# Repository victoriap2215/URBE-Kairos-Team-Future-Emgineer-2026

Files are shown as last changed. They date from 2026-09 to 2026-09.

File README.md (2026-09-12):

# Índice

# Índice

* [1. Nuestro Equipo](#1-nuestro-equipo)
  * [1.1 Integrantes](#11-integrantes)
  * [1.2 Nuestro Objetivo](#12-nuestro-objetivo)
  * [1.3 Contenido de la carpetas](#13-contenido-de-las-carpetas)
* [2. El Robot y Diseño Mecánico](#2-el-robot-y-diseño-mecánico)
  * [2.1 Chasis y Estructura](#21-chasis-y-estructura)
  * [2.2 Sistema de Dirección](#22-sistema-de-dirección)
  * [2.3 Sistema de Tracción](#23-sistema-de-tracción)
  * [2.4 Fotos del vehículo](#23-fotos-del-vehículo)
* [3. Apartado Electrónico](#3-apartado-electrónico)
  * [3.1 Microcontrolador y Sensores](#31-microcontrolador-y-sensores)
  * [3.2 Controlador de Motores](#32-controlador-de-motores)
  * [3.3 Baterías y Alimentación](#33-baterías-y-alimentación)
  * [3.4 Esquemas de Conexión](#34-esquemas-de-conexión)
* [4. Software y Control](#4-software-y-control)
  * [4.1 Visión Artificial](#41-visión-artificial)
  * [4.2 Algoritmo de Navegación](#42-algoritmo-de-navegación)
  
---

## 1. Nuestro Equipo
Somos Kairos, un grupo de estudiantes universitarios dedicados a la robótica, la automatización y la innovación tecnológica. 
### 1.1 Integrantes
<table>
  <tr>
    <td width="30%" valign="top">
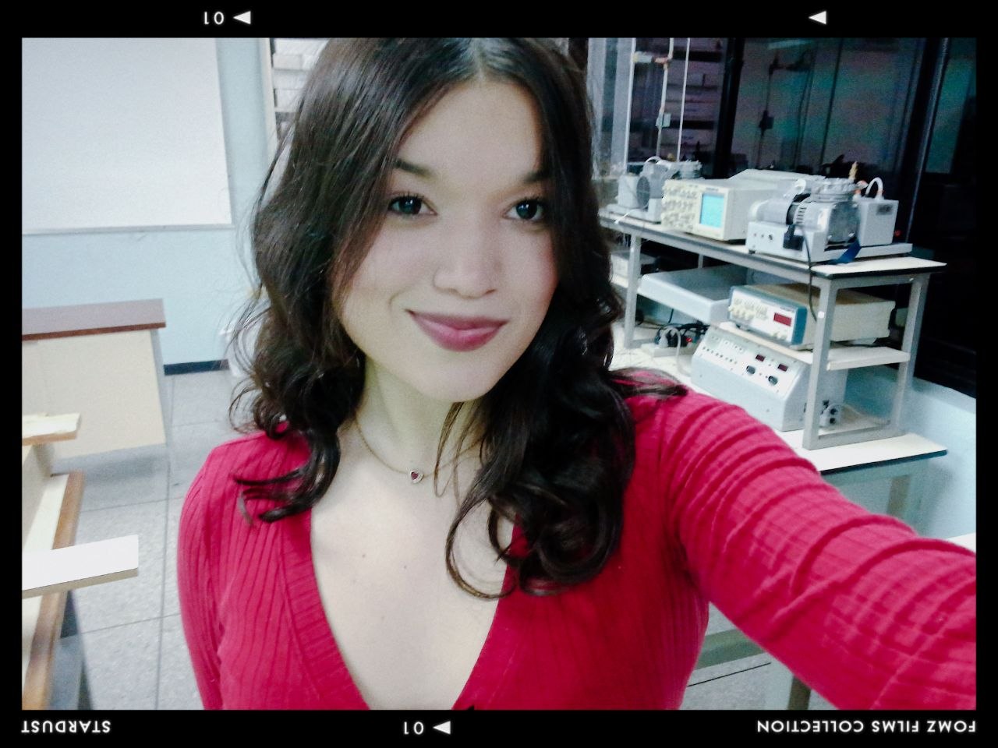
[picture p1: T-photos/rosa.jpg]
Rosalba Rodríguez
      
    </td>
    <td valign="top">
      <h3>Rosalba Rodríguez</h3>
      <p>🎂 <b>Edad:</b> [21] años</p>
      <p>🧑‍💻 <b>Rol:</b> Hardware / Electrónica</p>
      <hr>
      <p>🔩 <b>Habilidades:</b></p>
      <ul>
        <li>Estudiante de Ing. Electrónica (Mención Automatización y Control).</li>
        <li>Desarrollo de sistemas de control para robótica autónoma.</li>
      </ul>
      <p>
    </td>
  </tr>
</table>
<table>
  <tr>
    <td width="30%" valign="top">
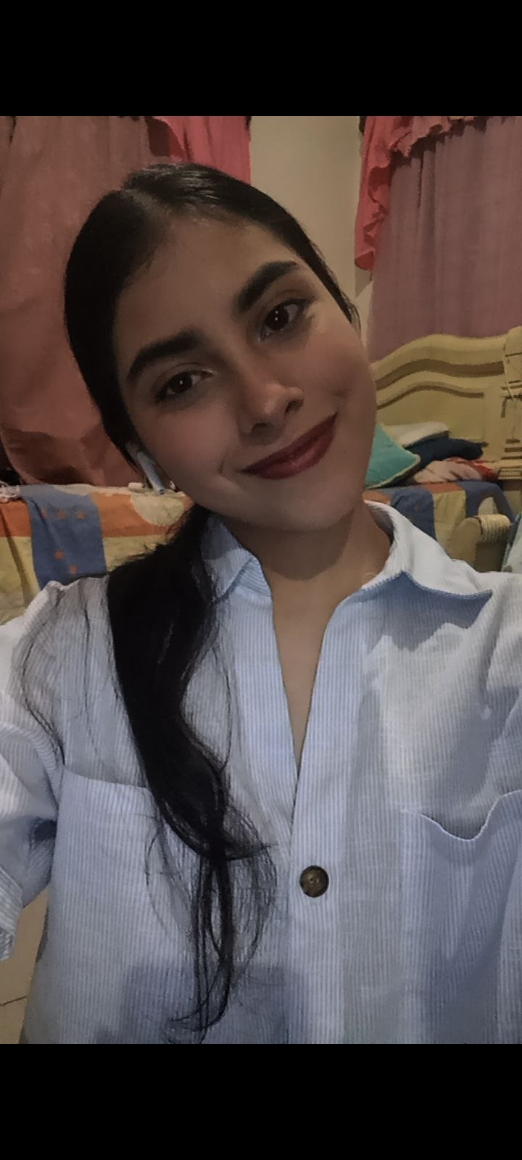
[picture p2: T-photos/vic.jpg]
Victoria Perozo
      
    </td>
    <td valign="top">
      <h3>Victoria Perozo</h3>
      <p>🎂 <b>Edad:</b> [20] años</p>
      <p>🧑‍💻 <b>Rol:</b> Documentación y Hardware / Electrónica</p>
      <hr>
      <p>🔩 <b>Habilidades:</b></p>
      <ul>
        <li>Estudiante de Ing. Electrónica (Mención Telecomunicaciones).</li>
        <li>Diseño y simulación de circuitos electrónicos.</li>
        <li>Desarrollo de sistemas de control para robótica autónoma.</li>    </td>
  </tr>
</table>
<table>
  <tr>
    <td width="30%" valign="top">
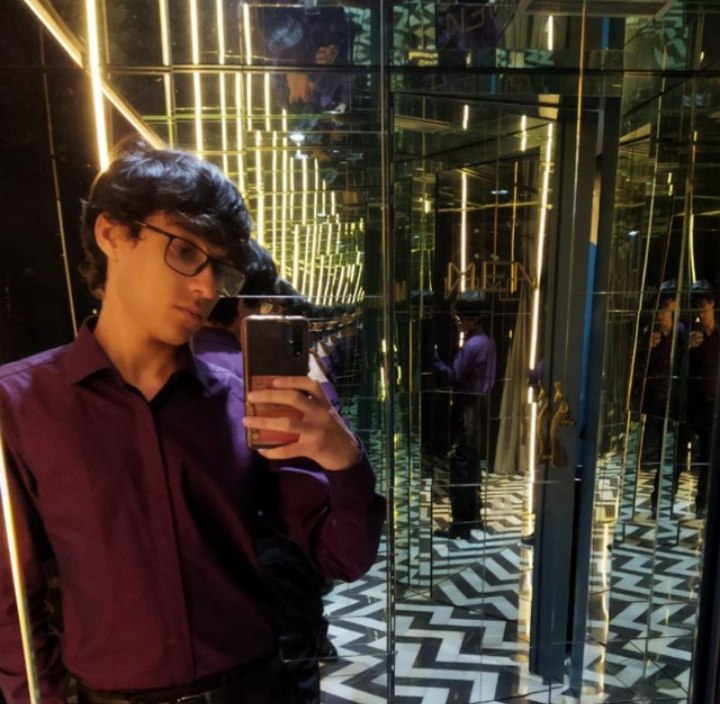
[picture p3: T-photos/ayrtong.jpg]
Ayrton Mrarcano
      
    </td>
    <td valign="top">
      <h3>Ayrton Marcano</h3>
      <p>🎂 <b>Edad:</b> [19] años</p>
      <p>🧑‍💻 <b>Rol:</b> Programación / Electrónica</p>
      <hr>
      <p>🔩 <b>Habilidades:</b></p>
      <ul>
        <li>Estudiante de Ing. Informatica.</li>
        <li>Programación de microcontroladores y sensores.</li>
        <li>Desarrollo de sistemas de control para robótica autónoma.</li>
    </td>
  </tr>
</table>

### 1.2 Nuestro Objetivo
Este proyecto tiene como objetivo diseñar, construir y programar un robot autónomo capaz de superar una serie de desafíos de obstáculos para la competición WRO Future Engineers. El equipo Kairos se inspiró en la aplicación de principios de ingeniería y en la resolución creativa y eficiente de problemas, impulsados por la pasión por la innovación y el aprendizaje práctico. 

Buscamos desarrollar un sistema fiable y eficiente que muestre nuestras competencias técnicas y de trabajo en equipo, y que además ofrezca una experiencia formativa profunda. Para lograrlo seguimos un proceso sistemático: investigación, prototipado, pruebas de laboratorio e iteraciones continuas. Mantenemos documentación detallada para facilitar la transferencia de conocimiento y asegurar un flujo de trabajo ordenado a lo largo del proyecto

### 1.3 Contenido de las carpetas
Contenido (Github) 
### *t-photos* contiene fotos del equipo

### *v-photos* contiene 6 fotos del vehículo desde varios ángulos

### *video* contiene el archivo video.md con el enlace a nuestro canal de YouTube y los vídeos correspondientes

### *models* es para los archivos 3D que usamos para imprimir nuestras piezas

### *other* incluye otros archivos que pueden usarse para entender cómo preparar el vehículo para la competición. Incluye documentación, conjuntos de datos, especificaciones de hardware, protocolos de comunicación, descripciones, etc.

### *schemes* contiene diagramas esquemáticos de los componentes electromecánicos que ilustran todos los elementos (componentes electrónicos y motores) utilizados en el vehículo y cómo se conectan entre sí.

### *src* contiene código de software de control para todos los componentes programados para participar en la competición

## 2. El Robot y Diseño Mecánico

### 2.1 Chasis y Estructura
Detalles de la estructura del vehículo.
 Se ha diseñado e impreso en 3D un complejo sistema de suspensión delantera de brazos superpuestos (double-wishbone) con amortiguadores simulados. Esto no solo eleva el chasis, sino que garantiza que las ruedas mantengan un contacto constante y uniforme con el tapete, incluso al pasar sobre pequeñas irregularidades o cables, asegurando una tracción máxima y constante.
Chasis Modular Elevado (Imagen 0): El chasis azul impreso en 3D ahora sitúa toda la electrónica crítica (Arduino Mega, portabaterías de 18650, driver de motores L298N) por encima del eje de las ruedas. Esto libera espacio inferior y evita cualquier tipo de rozamiento.
Ruedas de Mayor Diámetro y Agarre: Se seleccionaron ruedas con un compuesto de goma con mejor coeficiente de fricción y mayor diámetro para contribuir a la elevación general y mejorar la capacidad de superar obstáculos menores.

### 2.2 Sistema de Dirección
### Servomotor: MG996R

<table>
  <tr>
    <td width="30%" valign="top" align="center">
      <br>
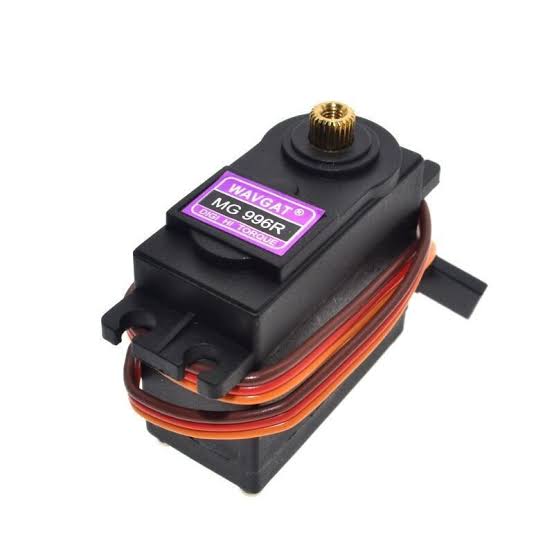
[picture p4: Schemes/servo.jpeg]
Servomotor MG996R
      
    </td>
    <td valign="top">
      <h4>Especificaciones:</h4>
      <table>
        <tr><td><b>Velocidad de operación</b></td><td>0.14 s/60°</td></tr>
        <tr><td><b>Voltaje de operación</b></td><td>6v DC</td></tr>
        <tr><td><b>Corriente de operación</b></td><td>500 mA – 900 mA</td></tr>
        <tr><td><b>Corriente de bloqueo</b></td><td>2.5 A</td></tr>
        <tr><td><b>Par de bloqueo</b></td><td>11.0 kg·cm</td></tr>
        <tr><td><b>Material de engranajes</b></td><td>metálico</td></tr>
        <tr><td><b>Peso</b></td><td>55 g</td></tr>
        <tr><td><b>Tipo de servo</b></td><td>Estándar / Posicional (180°)</td></tr>
        <tr><td><b>Datasheet</b></td><td><a href="URL_DEL_DATASHEET" target="_blank">MG996R Tower-Pro</a></td></tr>
      </table>
    </td>
  </tr>
</table>

### Dimensión mecánica
dim servo

Para hacer una buena elección se hizo la comparación con el micro-servo SG90. Aunque ambos se controlan por PWM y tienen un recorrido de 180°, el SG90 usa engranajes de plástico, opera a un voltaje de 4.8V y entrega un torque máximo de apenas 1.8 kg·cm, lo que lo hace más propenso al desgaste en sus engranajes o romperse debido al peso del chasis en movimiento, en cambio, el MG996R ofrece un torque de bloqueo que alcanza aproximadamente 11 kg·cm a 6V, por lo que dispone de un margen de trabajo mucho mayor para vencer la resistencia del sistema de varillas, la fricción del pivote y las irregularidades de la pista, lo que le da la robustez necesaria para mantener la alineación de las ruedas y reducir el desgaste en el sistema de varillas de dirección. 

### *Motivo de la elección:* 

Para la dirección del robot, elegimos el servomotor MG996R de giro estándar, por su buena resistencia mecánica y sus engranajes metálicos, que son importantes para soportar las cargas del eje delantero. Además, su control por PWM facilita conectarlo directamente con el microcontrolador, lo que permite una respuesta rápida y precisa. 

La dirección fue diseñada bajo la geometría Ackermann porque se busca que el robot tenga un giro más suave y eficiente, reduciendo el deslizamiento de las ruedas. A diferencia de un sistema de dirección paralela, esta configuración mejora la maniobrabilidad en espacios pequeños y ayuda a mantener una alineación más exacta al estacionar o esquivar obstáculos. 

### *Justificación técnica:* 

ackerman

Utilizamos un sistema de dirección Ackermann diseñado y fabricado a medida mediante impresión 3D. Este mecanismo permite que las ruedas delanteras giren con ángulos ligeramente diferentes en cada curva, de modo que ambas sigan trayectorias concéntricas hacia un mismo punto sobre el eje trasero. Esta configuración mejora la estabilidad y la precisión en los giros cerrados. El diseño fue ajustado de forma interactiva en FreeCAD, modificando los puntos de giros y los ángulos de dirección hasta lograr una aproximación adecuada a la configuración Ackermann. 

La calibración del sistema se realizó verificando la posición neutra del servomotor antes del montaje definitivo, es decir, lo primero que se realizó fue conectar el servo al Arduino y ordenarle un ángulo de 90° antes de su montaje, para así asegurar que el motor estuviera centrado y no forzar ni romper las piezas. Con el servo fijo en ese punto, se procedió al montaje del brazo de dirección y acoplamiento de las varillas de la geometría Ackermann intentando que las ruedas delanteras quedaran lo más centradas posible. A partir de esa referencia, se hicieron pruebas en la pista y ajustes en el código para corregir desviaciones y asegurar que el giro a ambos lados fuera simétrico. De esta manera, se aseguró que el sistema quedara centrado y que las correcciones de dirección respondieran con precisión a las órdenes del microcontrolador.  

La geometría Ackermann fue adaptada a las dimensiones y curvas de la pista para asegurar que el vehículo tuviera buena reacción a las curvas cerradas y la mínima pérdida de adherencia posible. Por consiguiente, se ajustaron los ángulos de dirección y la posición de los puntos de giro en el modelo impreso en 3D, buscando que las ruedas delanteras trazaran una trayectoria coherente con el radio de curvatura de la pista durante las maniobras. Este ajuste permitió mejorar la estabilidad del robot, especialmente en cambios de dirección bruscos y en el paso por obstáculos. 
 
### *Cálculos:* 

### Ecuación Fundamental
cot(θ o ) - cot(θ i ) = W / L

W : Distancia entre pivotes de dirección (batalla)
L : Distancia entre ejes

### Relación de Velocidades en Curva
ω o / ω i = (R + W/2) / (R - W/2)

ω o : Velocidad angular de la rueda exterior.
ω i : Velocidad angular de la rueda interior.
R : Radio de giro del centro del eje.

### *Montaje:* 

El servomotor está en una plataforma de soporte frontal integrada en el chasis, la cual conecta con el varillaje del mecanismo de dirección.  El diseño modular permite realizar ajustes o cambios de componentes de manera sencilla. 

### 2.3 Sistema de Tracción
### Motor: Motorreductor DC

<table>
  <tr>
    <td width="30%" valign="top" align="center">
      <br>
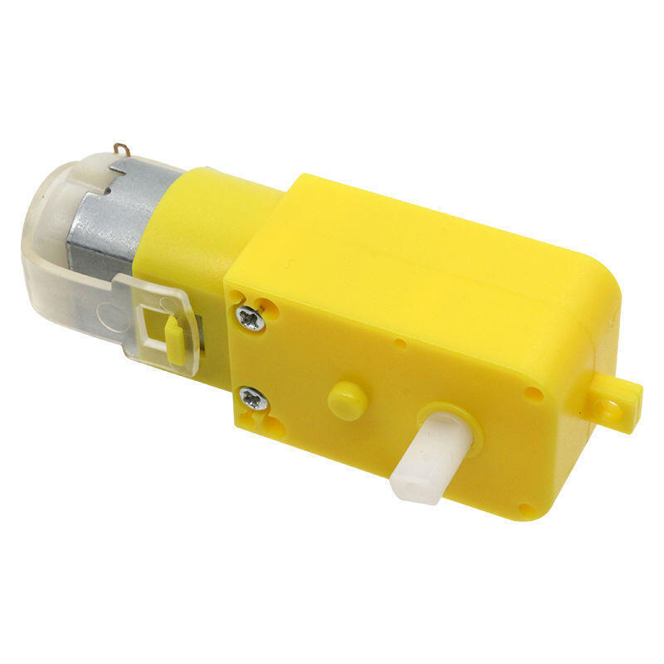
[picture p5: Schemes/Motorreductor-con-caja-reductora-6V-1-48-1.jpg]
Motorreductor DC
      
    </td>jp
    <td valign="top">
      <h4>Especificaciones:</h4>
      <table>
        <tr><td><b>Voltaje</b></td><td>12v DC</td></tr>
        <tr><td><b>Velocidad sin carga (RPM)</b></td><td>200rpm</td></tr>
        <tr><td><b>Par de motor de pérdida</b></td><td>1.7 kg-cm</td></tr>
        <tr><td><b>Par máximo de eficiencia</b></td><td>0.34 kg-cm</td></tr>
        <tr><td><b>Relación de cambios</b></td><td>1:100</td></tr>
        <tr><td><b>Corriente nominal</b></td><td>0.04 A</td></tr>
        <tr><td><b>Corriente de pérdida</b></td><td>0.67 A</td></tr>
        <tr><td><b>Material de engranajes</b></td><td>metálico</td></tr>
        <tr><td><b>Datasheet</b></td><td><a href="https://www.bolanosdj.com.ar/MOVIL/ARDUINO2/MotoresConRuedasArd.pdf" target="_blank">MotoresConRuedasArd.pdf</a></td></tr>
      </table>
    </td>
  </tr>
</table>

### Dimensión mecánica
dig moto

### *Motivo de la elección*

El motorreductor amarillo DC fue seleccionado por su diseño ligero, económico y su facilidad de integración dentro de nuestro chasis. Su caja reductora integrada permite una transmisión directa y eficiente hacia las ruedas, proporcionando el par necesario para mantener una buena tracción en pistas planas dentro de una arquitectura modular.

Al no contar con un encoder (codificador) integrado para el conteo de vueltas, se incorporó un giroscopio que ofrece una retroalimentación de movimiento precisa. Esto asegura que los desplazamientos del robot sean exactos, compensando la ausencia de sensores de efecto Hall y reduciendo el margen de error al tomar curvas cerradas.

### *Justificación técnica* 

Elegimos el motorreductor amarillo DC con su relación de reducción interna (1:48) porque nos ofrece el balance ideal entre torque, velocidad de respuesta y consumo energético. Esta configuración permite alcanzar la velocidad requerida en las ruedas para que los sensores de visión artificial y los sensores ultrasónicos ejecuten la captura y el procesamiento de datos en tiempo real con alta estabilidad, evitando desincronizaciones en las lecturas durante los giros.

Utilizando los modelos de transferencia de torque y considerando el peso total del chasis junto con la fricción de los ejes, los cálculos determinan que el torque requerido para vencer la fricción estática inicial y poner en marcha el robot se encuentra muy por debajo del torque máximo de pérdida especificado para estos motores. Este margen garantiza un factor de seguridad óptimo sobre el torque mínimo de arranque, asegurando que los motores operen de forma continua en su zona de mayor eficiencia sin sobrecalentamiento.

### *Diferencial de engranaje (Diseño principal)*

Originalmente se diseñó un sistema de engranajes diferencial impreso en 3D para ser acoplado al conjunto del motorreductor amarillo. Este mecanismo permitiría que las ruedas traseras (izquierda y derecha) giraran a velocidades independientes durante las curvas, optimizando el desplazamiento fluido y mejorando la estabilidad del robot en giros exigentes. Sin embargo, debido a fallos en la manufactura de las piezas mecánicas, no fue posible su implementación en el prototipo final.
Solución del diseño

Durante la fase de ensamblaje se identificó un error de tolerancia en la impresión de los engranajes internos del diferencial (el anillo y los piñones satélite). Ante la imposibilidad de reimprimir estas piezas a tiempo para las pruebas, se sustituyó la caja del diferencial por un sistema de transmisión de eje rígido directo.

Aunque esta modificación elimina la capacidad mecánica de variar la velocidad entre ambas ruedas al girar, el efecto se compensa a través de código: el software utiliza los datos del giroscopio para ajustar la aceleración y gestionar electrónicamente la trayectoria del vehículo en las curvas.

### Fotos del vehículo

### 1.2 Imágenes del Robot

<table>
  <tr>
    <td align="center">
      <b>Vista frontal</b><br>
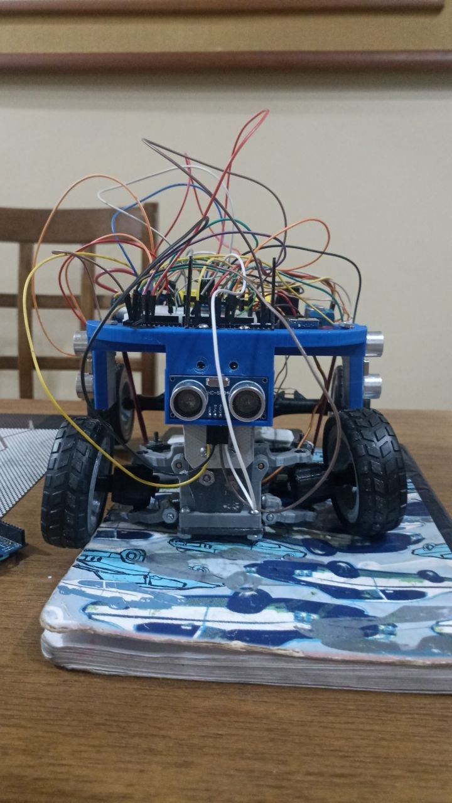
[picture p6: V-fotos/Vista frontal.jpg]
Vista frontal
      
    </td>
    <td align="center">
      <b>Vista posterior</b><br>
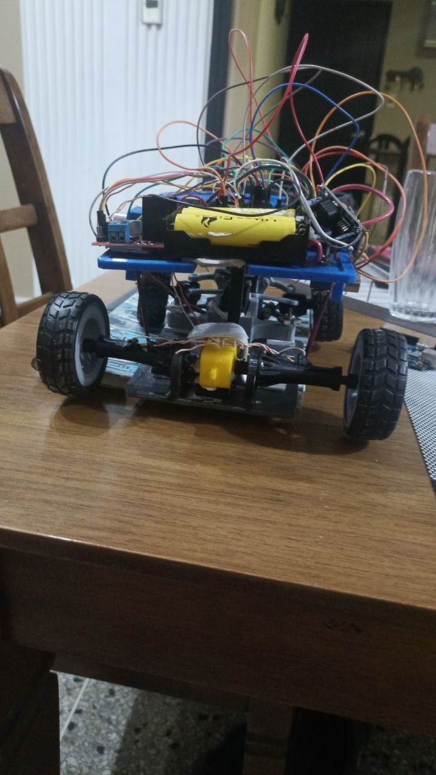
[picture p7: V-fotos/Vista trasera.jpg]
Vista posterior
      
    </td>
    <td align="center">
      <b>Vista lateral izquierda</b><br>
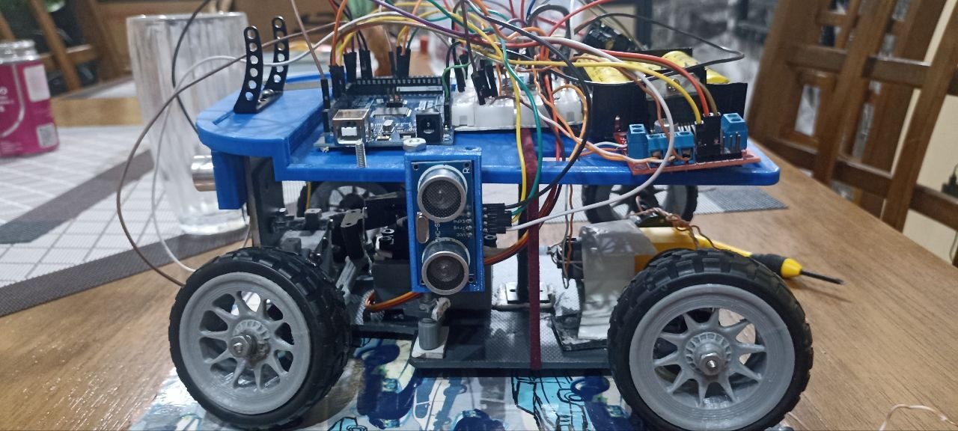
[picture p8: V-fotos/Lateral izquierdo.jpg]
Vista lateral izquierda
      
    </td>
  </tr>
  <tr>
    <td align="center">
      <b>Vista lateral derecha</b><br>
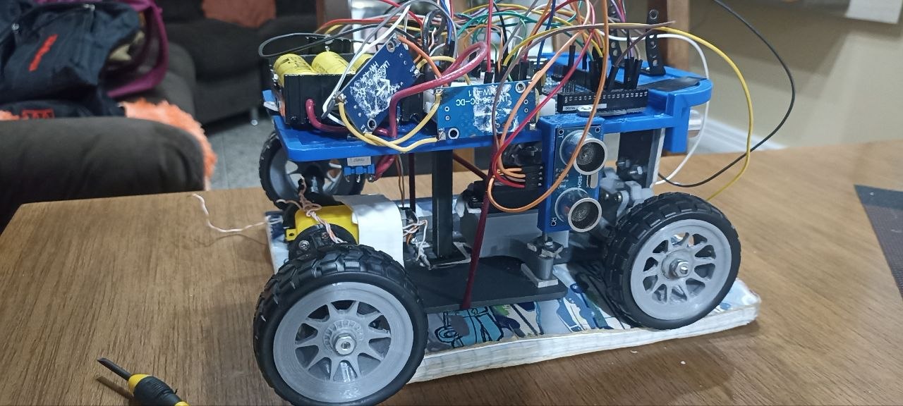
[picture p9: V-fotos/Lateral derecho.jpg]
Vista lateral derecha
      
    </td>
    <td align="center">
      <b>Vista superior</b><br>
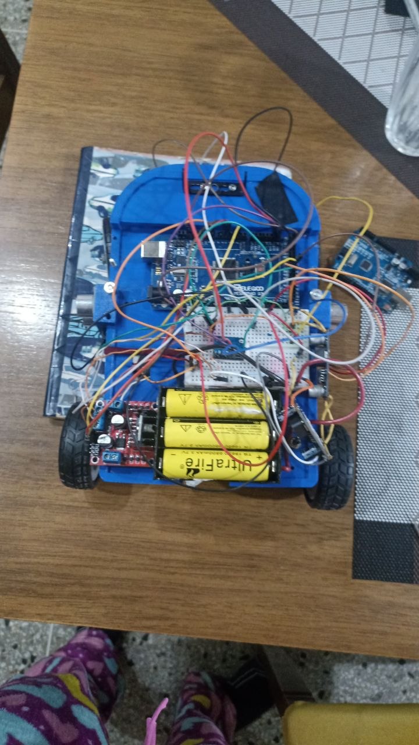
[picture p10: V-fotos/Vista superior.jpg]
Vista superior
      
    </td>
    <td align="center">
      <b>Vista inferior</b><br>
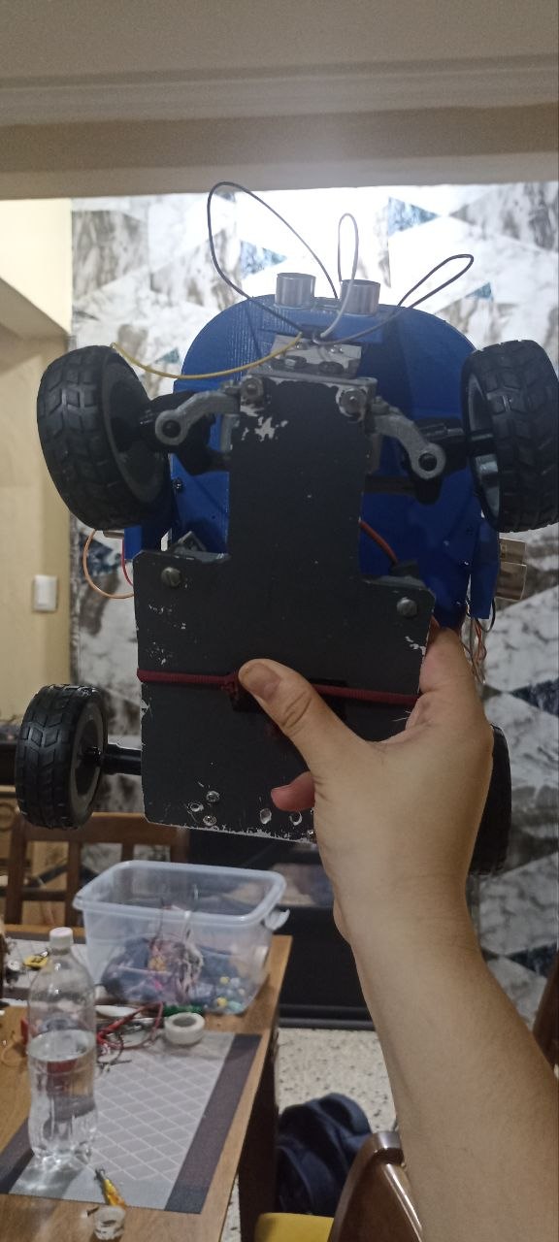
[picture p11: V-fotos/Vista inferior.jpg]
Vista inferior
      
    </td>
  </tr>
</table>

## 3. Apartado Electrónico
### 3.1 Microcontrolador y Sensores
### Microcontrolador: Arduino Mega2560

<table>
  <tr>
    <td width="30%" valign="top" align="center">
      <br>
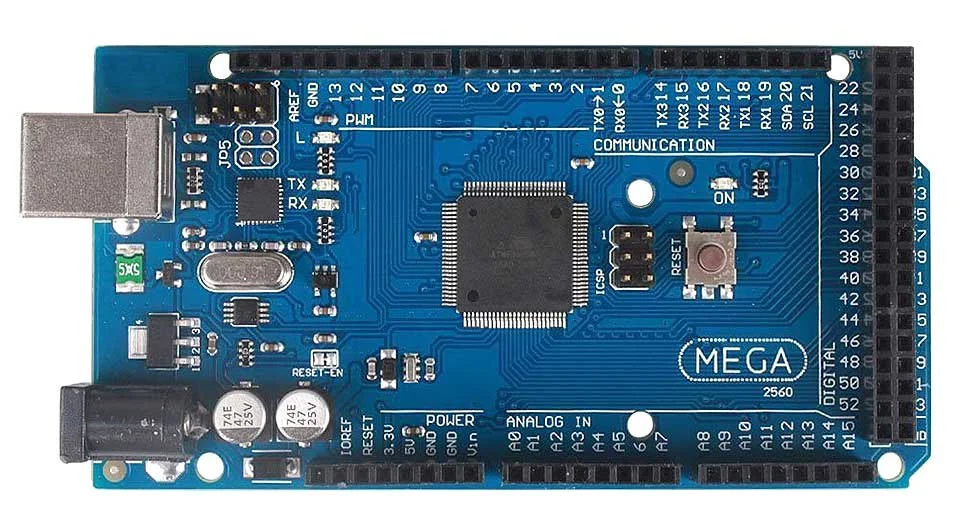
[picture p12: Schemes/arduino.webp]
Arduino Mega2560
      
    </td>
    <td valign="top">
      <h4>Especificaciones:</h4>
      <table>
        <tr><td><b>Microcontrolador</b></td><td>ATmega2560</td></tr>
        <tr><td><b>Coprocesador Inalámbrico</b></td><td>ESP8266 integrado (Para conectividad WiFi)</td></tr>
        <tr><td><b>Voltaje de operación</b></td><td>5 V DC</td></tr>
        <tr><td><b>Voltaje de Entrada</b></td><td>7V a 12V DC</td></tr>
        <tr><td><b>Pines I/O Digitales</b></td><td>54 (de los cuales 15 proporcionan salida PWM)</td></tr>
        <tr><td><b>Pines de Entrada Analógica</b></td><td>16</td></tr>
        <tr><td><b>Memoria Flash</b></td><td>256 KB (de los cuales 8 KB son usados por el bootloader)</td></tr>
        <tr><td><b>Memoria SRAM / EEPROM</b></td><td>8 KB / 4 KB</td></tr>
        <tr><td><b>Datasheet</b></td><td><a href="https://admin.arsbook.it/stempdf/LS-ELEGOO-MEGA.pdf" target="_blank">LS-ELEGOO-MEGA.pdf</a></td></tr>
      </table>
    </td>
  </tr>
</table>

### Motivo de la selección

El Arduino Mega 2560 actúa como el cerebro central de procesamiento de nuestro robot. Su arquitectura basada en el microcontrolador ATmega2560 ofrece una ejecución de muy baja latencia, lo cual resulta indispensable para responder en tiempo real a las lecturas del giroscopio MPU6050, el procesamiento del sistema de visión artificial y la evasión instantánea de obstáculos mediante los sensores ultrasónicos.

Elegimos esta tarjeta debido a la alta demanda de recursos de nuestra arquitectura electrónica y de control. Al integrar simultáneamente la cámara de visión artificial, los sensores ultrasónicos, el módulo IMU MPU6050, el servomotor de dirección y el driver de tracción, placas más compactas habrían agotado rápidamente sus pines disponibles y su memoria de trabajo. Además, este modelo incorpora un coprocesador inalámbrico ESP8266 integrado, lo que nos otorga conectividad WiFi para la transmisión de telemetría sin recargar las tareas principales del procesador central. Sus 54 pines digitales, 16 entradas analógicas y 4 puertos UART por hardware nos dan total libertad para mantener un esquema de cableado modular, ordenado y directo.

### Comparación con Arduino Uno y Nano

Al comparar la tarjeta seleccionada con un Arduino Uno o Nano tradicional, la diferencia más crítica radica en la capacidad de memoria y procesamiento. El Arduino Mega 2560 cuenta con 256 KB de memoria Flash y 8 KB de memoria SRAM, lo que representa hasta ocho veces más espacio para alojar algoritmos de control de trayectoria, cálculos de visión y librerías complejas sin correr el riesgo de colapsar la memoria del sistema durante la ejecución en pista.

Otra ventaja determinante es la disponibilidad de periféricos por hardware. Mientras que placas como el Uno poseen un solo puerto serie, el Mega 2560 ofrece 4 puertos UART independientes por hardware, lo que permite la comunicación simultánea con la cámara de visión y el monitor de depuración sin recurrir a emulaciones por software. Asimismo, sus 54 pines de entrada/salida digital evitan la saturación del controlador al conectar múltiples sensores y actuadores de forma dedicada, sumado a la conectividad WiFi integrada mediante el chip ESP8266 que no está presente en los modelos convencionales.

### Justificación de la ubicación

El Arduino Mega 2560 se posicionó en el centro geométrico del chasis con el objetivo principal de garantizar su protección estructural. Al ubicarse en la zona interna más resguardada del vehículo, la tarjeta queda protegida frente a posibles colisiones directas o roces accidentales contra las paredes del circuito durante la navegación.

Adicionalmente, esta posición estratégica optimiza la distribución general del cableado. Estar en el centro minimiza la distancia física hacia los componentes de la sección frontal (como la cámara de visión, el servomotor de dirección y los sensores ultrasónicos) y hacia la sección trasera (donde se encuentran el driver de potencia y el motor de tracción). Esto no solo ayuda a reducir el peso total de los cables y a equilibrar las masas del robot, sino que también disminuye notablemente el riesgo de interferencias electromagnéticas en las líneas de transmisión de datos.
Cámara, MPU6050, sensores ultrasónicos, etc.

### Sensor Ultrasónico: HC-SR04

<table>
  <tr>
    <td width="30%" valign="top" align="center">
      <br>
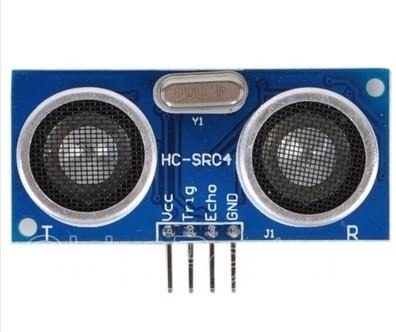
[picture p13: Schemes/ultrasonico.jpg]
Sensor Ultrasónico HC-SR04
      
    </td>
    <td valign="top">
      <h4>Especificaciones:</h4>
      <table>
        <tr><td><b>Modelo</b></td><td>HC-SR04</td></tr>
        <tr><td><b>Voltaje</b></td><td>5 V DC</td></tr>
        <tr><td><b>Corriente de trabajo</b></td><td>15 mA</td></tr>
        <tr><td><b>Corriente de reposo</b></td><td>&lt; 2mA</td></tr>
        <tr><td><b>Rango de medición</b></td><td>2 cm a 400 cm</td></tr>
        <tr><td><b>Ángulo de apertura</b></td><td>&lt; 15° (Cono de medición)</td></tr>
        <tr><td><b>Datasheet</b></td><td><a href="URL_DEL_DATASHEET" target="_blank">ULTRASONIC-HC-SR04.PDF</a></td></tr>
      </table>
    </td>
  </tr>
</table>

### Dimensiones mecánicas
dim sensor

### Motivo de la elección: 

Hemos integrado dos sensores ultrasónicos para la navegación en entornos con obstáculos, estos sensores son importantes para la detección de distancias de seguridad para evitar colisiones. El funcionamiento de estos dispositivos se basa en la emisión de pulsos sonoros y la medición del tiempo de retorno, lo que permite calcular la distancia a paredes o pilares con alta precisión, sin depender de las condiciones de luz, proporcionando seguridad para tareas como el aparcamiento en paralelo. 

Estos sensores ofrecen una ventaja competitiva frente a los infrarrojos, ya que al no depender de la iluminación del entorno permite una detección constante sobre cualquier tipo de material. Además, al tener una fácil conexión con el microcontrolador, permite una rápida integración. 

### Justificación de la ubicación: 

La aplicación de los ultrasónicos consta de tres sensores posicionados a los costados y al frente del robot, uno en el lado izquierdo y otro en el lado derecho. Esta distribución se aplica para compensar las zonas ciegas y complementar el campo de visión de la cámara. 

Al colocar la cámara en la parte frontal para el reconocimiento de colores y líneas de carrera, sus laterales se convierten en puntos ciegos en el campo de visión, debido al ángulo de su lente. Por ello, se decidió colocar los sensores posicionados hacia los laterales y al frente, para que cubran los puntos críticos de visión durante el recorrido, esta configuración nos ayuda a ejecutar maniobras como el aparcamiento en paralelo o la evasión de pilares en curvas cerradas, ya que permite medir la distancia de las paredes de la pista.

### Sensor de Orientación: Giroscopio

<table>
  <tr>
    <td width="30%" valign="top" align="center">
      <br>
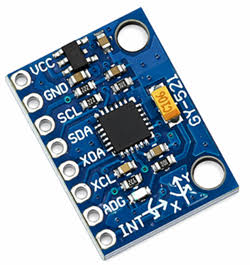
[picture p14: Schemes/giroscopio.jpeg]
Sensor MPU6050
      
    </td>
    <td valign="top">
      <h4>Especificaciones:</h4>
      <table>
        <tr><td><b>Modelo</b></td><td>MPU6050 (Acelerómetro + Giroscopio de 6 ejes)</td></tr>
        <tr><td><b>Voltaje</b></td><td>3.3 V a 5 V DC</td></tr>
        <tr><td><b>Corriente de operación</b></td><td>3.9 mA</td></tr>
        <tr><td><b>Protocolo de comunicación</b></td><td>I2C (pines SDA y SCL)</td></tr>
        <tr><td><b>Convertidores Analógico-Digital (ADC)</b></td><td>De 16 bits para cada eje</td></tr>
        <tr><td><b>Datasheet</b></td><td><a href="URL_DEL_DATASHEET" target="_blank">ps-mpu-6000a-00-mpu-6000-and-mpu-6050-datasheet.pdf</a></td></tr>
      </table>
    </td>
  </tr>
</table>

### Diagrama de bloque interno 
dig giro

### Motivo de la selección

El módulo MPU6050 es de suma importancia para la navegación y el control de rumbo de nuestro robot, especialmente debido a que nuestra configuración de tracción con el motorreductor amarillo DC no cuenta con encoders para medir directamente las revoluciones o vueltas de las ruedas, ante esta limitación, la Unidad de Medida Inercial (IMU) proporciona lecturas en tiempo real sobre la velocidad angular y el ángulo de orientación (yaw), permitiendo que el sistema realice correcciones continuas para mantener el rumbo o ejecutar giros exactos.

Elegimos el MPU6050 por ser una solución compacta e integral, ya que reúne en un solo chip un giroscopio de 3 ejes y un acelerómetro de 3 ejes, ofreciendo un sistema de navegación inercial completo de 6 grados de libertad (6-DOF). La mayor ventaja técnica de este módulo es su procesador interno Digital Motion Processor (DMP), el cual ejecuta de forma autónoma los cálculos matemáticos pesados para el filtrado de ruido y fusión de datos. Gracias a esto, el MPU6050 entrega los datos de orientación ya procesados y limpios, liberando de esa carga de trabajo a nuestro Arduino Mega 2560.

### Comparación con otras alternativas de orientación

Al comparar el MPU6050 con el uso de sensores individuales o con brújulas digitales magnéticas (como el HMC5883L), el MPU6050 presenta ventajas superiores de integración y precisión en robótica móvil. Las brújulas magnéticas son altamente susceptibles a las interferencias electromagnéticas generadas por el propio motorreductor amarillo DC en funcionamiento y por el cableado de potencia, lo que provoca desviaciones severas en la lectura de dirección. Al ser puramente inercial, el MPU6050 no se ve afectado por campos magnéticos externos.

Por otro lado, implementar sensores de inclinación o aceleración independientes requeriría mayor cableado en el bus I2C y obligaría al microcontrolador a ejecutar manualmente algoritmos de filtrado pesados (como el filtro de Kalman o complementario), consumiendo memoria y ciclos de procesamiento. El MPU6050 resuelve esto mediante su DMP interno, representando la opción más equilibrada entre precisión, bajo consumo y eficiencia de procesamiento.

### Justificación de la ubicación

El MPU6050 se ubicó en la zona central del chasis, situándose lo más cerca posible del centro de masa y del eje geométrico de rotación del robot. Esta ubicación es crítica, ya que situar el giroscopio lejos del centro de giro introduce aceleraciones centrípetas parasitarias durante las curvas, deformando las lecturas.
Adicionalmente, al estar montado de forma rígida sobre una sección estable del chasis, se reducen las vibraciones mecánicas generadas por el motorreductor amarillo y la rodadura, asegurando una transmisión constante de datos estables a través de las líneas de comunicación I2C.

### Cámara de Visión Artificial: HuskyLens 2

<table>
  <tr>
    <td width="30%" valign="top" align="center">
      <br>
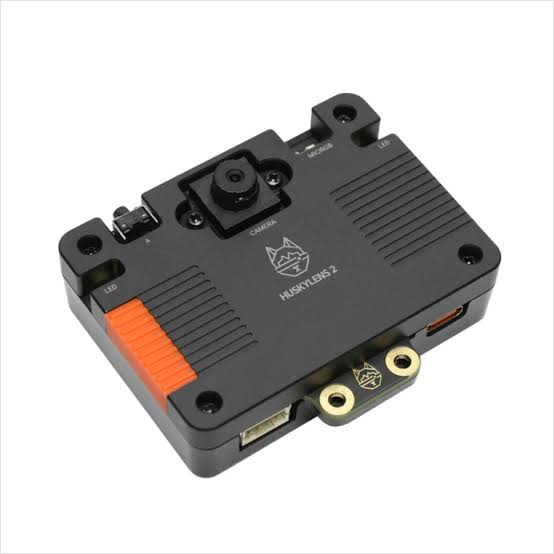
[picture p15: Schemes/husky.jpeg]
Cámara HuskyLens 2
      
    </td>
    <td valign="top">
      <h4>Especificaciones:</h4>
      <table>
        <tr><td><b>Procesador principal</b></td><td>Kendryte K230 Dual-Core a 1.6 GHz</td></tr>
        <tr><td><b>Sensor de imagen</b></td><td>GC2093 de 2.0 Megapíxeles (1/2.9", hasta 60 FPS)</td></tr>
        <tr><td><b>Pantalla</b></td><td>IPS táctil capacitiva de 2.4" (Resolución 640 × 480)</td></tr>
        <tr><td><b>Memoria</b></td><td>1 GB LPDDR4 RAM + 8 GB eMMC Flash</td></tr>
        <tr><td><b>Voltaje de operación</b></td><td>3.3V a 5.0V DC (a través del puerto Gravity o USB-C)</td></tr>
        <tr><td><b>Consumo de Corriente</b></td><td>1.5W – 3W (aprox. 300 mA a 600 mA a 5V)</td></tr>
        <tr><td><b>Tipo de Lente</b></td><td>Módulo intercambiable de lente modular</td></tr>
        <tr><td><b>Interfaces de datos</b></td><td>UART serial (baud rates 9600, 115200), I2C (dirección default 0x50), USB-C y Wi-Fi 6 (módulo opcional)</td></tr>
        <tr><td><b>Datasheet</b></td><td><a href="https://www.farnell.com/datasheets/3178377.pdf" target="_blank">3178377.pdf</a></td></tr>
      </table>
    </td>
  </tr>
</table>

### Motivo de la selección

La cámara de visión artificial HuskyLens 2 actúa como el sensor primario de percepción visual de nuestro robot. A diferencia de las cámaras convencionales, cuenta con un procesador dedicado Kendryte K230 Dual-Core a 1.6 GHz con aceleración por Inteligencia Artificial que procesa las imágenes internamente a 60 FPS. Esto permite detectar y rastrear objetos, firmas de color y marcadores visuales con alta precisión sin recargar de procesamiento al microcontrolador principal Arduino Mega 2560. Su diseño compacto y ligereza facilitan una integración eficiente en la estructura, utilizándose principalmente para:

 * Identificar y diferenciar el color y tipo de pilares u obstáculos en la pista.
 * Seguir líneas de ruta y límites del circuito.
 * Reconocer zonas de maniobra, señales y marcadores visuales en tiempo real.
 * 
### Comparación con la PixyCam2

Al comparar la HuskyLens 2 con la PixyCam2, la diferencia técnica más destacada se encuentra en la potencia de procesamiento y las capacidades de Inteligencia Artificial en el borde (Edge AI). Mientras que la PixyCam2 utiliza un procesador NXP dual-core a 204 MHz enfocado en la filtración de color por tono y saturación, la HuskyLens 2 integra un procesador Kendryte K230 a 1.6 GHz respaldado por 1 GB de memoria RAM LPDDR4 y 8 GB de almacenamiento eMMC. Esta diferencia de capacidad computacional permite a la HuskyLens 2 ejecutar modelos de visión e inferencias de IA significativamente más complejas y estables ante variaciones de escena.

Otra ventaja operativa determinante es la presencia de su pantalla táctil IPS de 2.4 pulgadas. La PixyCam2 carece de pantalla integrada, lo que obliga a conectar la cámara a una computadora portátil mediante el software PixyMon para ajustar o reentrenar algoritmos. En cambio, la HuskyLens 2 permite realizar la calibración, el aprendizaje de nuevas firmas de color y el ajuste de parámetros de detección directamente en la cámara mediante su interfaz táctil, acelerando drásticamente la puesta a punto del robot en la pista de competencia.

### Justificación de la ubicación y calibración

La HuskyLens 2 se montó de forma rígida en la parte frontal del vehículo sobre un soporte elevado. Esta posición otorga a la lente un ángulo despejado de la pista, permitiendo captar colores, referencias y límites sin que el chasis o el sistema de dirección obstaculicen la toma de imagen. La elevación estratégica permite anticipar las curvas, detectar con suficiente margen de distancia los pilares de color y enviar los datos de posición al Arduino para ejecutar giros suaves y precisos.
Para evitar errores de detección causados por variaciones en la iluminación del recinto (que suelen alterar la visión espectral y la temperatura de color), la cámara se calibra previamente a las pruebas.

### 3.2 Controlador de Motores
### Módulo Driver de Motores: Puente H L298N

<table>
  <tr>
    <td width="30%" valign="top" align="center">
      <br>
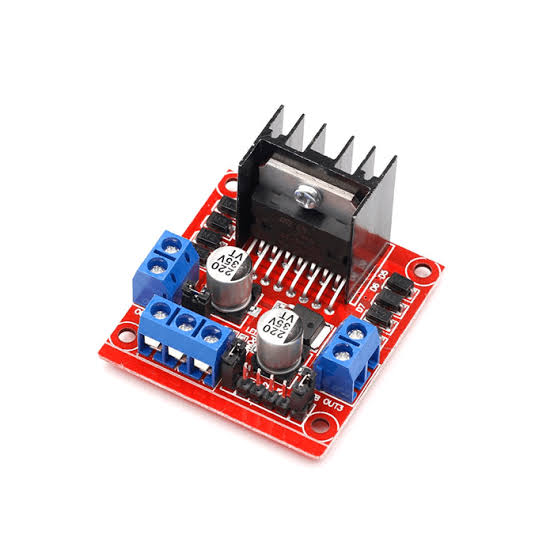
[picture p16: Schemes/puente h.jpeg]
Módulo Driver Puente H L298N
      
    </td>
    <td valign="top">
      <h4>Especificaciones:</h4>
      <table>
        <tr><td><b>Modelo</b></td><td>L298n (Módulo Driver Puente H Dual)</td></tr>
        <tr><td><b>Voltaje de entrada</b></td><td>5 V – 35 V (para los motores)</td></tr>
        <tr><td><b>Voltaje de lógica</b></td><td>5 V (para el Arduino)</td></tr>
        <tr><td><b>Corriente máxima</b></td><td>2A por canal</td></tr>
        <tr><td><b>Corriente continua</b></td><td>1A – 1.5A por motor (recomendado)</td></tr>
        <tr><td><b>Potencia máxima disipada</b></td><td>25W</td></tr>
        <tr><td><b>Motores controlables</b></td><td>2 motores DC o 1 paso a paso (bipolar)</td></tr>
        <tr><td><b>Datasheet</b></td><td><a href="URL_DEL_DATASHEET" target="_blank">Datasheet - L298 - Dual full-bridge driver</a></td></tr>
      </table>
    </td>
  </tr>
</table>

### Motivo de la elección

Para la gestión de la movilidad y el sistema de tracción, optamos por el módulo L298N como el puente H encargado de regular la velocidad mediante modulación por ancho de pulso (PWM) y el sentido de giro de nuestro motorreductor amarillo DC. Este módulo trabaja recibiendo señales de control de baja potencia desde el microcontrolador y las amplifica mediante su etapa de potencia para suministrar el voltaje adecuado al motor de tracción. Seleccionamos este componente por su plena compatibilidad con los niveles lógicos de 5V del Arduino Mega 2560, lo que garantiza una comunicación directa sin necesidad de acondicionadores de señal ni adaptadores de nivel.

Adicionalmente, el L298N nos facilita el montaje modular dentro del chasis gracias a sus borneras de tornillo integradas y a su robusto disipador térmico de aluminio. Estas ventajas mecánicas permiten asegurar las conexiones de alta corriente fuertemente con un destornillador, logrando un acople firme que previene desconexiones accidentales por vibración en la pista. Esto protege la estabilidad de toda la arquitectura electrónica, asegurando un suministro eléctrico aislado respecto a componentes sensibles como la cámara de visión artificial HuskyLens 2, el módulo inercial MPU6050 y los sensores ultrasónicos HC-SR04.

### Comparación con otros drivers de motores

Al comparar el L298N con alternativas populares como el driver TB6612FNG o el módulo L9110S, la principal ventaja para nuestro proyecto radica en la disipación térmica y la robustez mecánica. El TB6612FNG utiliza MOSFETs de mayor eficiencia que reducen la caída de voltaje interna; sin embargo, al ser un chip compacto de montaje superficial, no incluye conectores de bornera integrados. Conectar los cables exige soldadura directa o pines finos que resultan frágiles ante las vibraciones mecánicas continuas del vehículo.

Por otro lado, el módulo L9110S es de menor tamaño pero carece de un disipador de calor dedicado, lo que limita su capacidad para soportar picos de corriente bajo exigencia continua. El L298N destaca sobre ambas opciones por su capacidad de disipar corriente constante de hasta 2A por canal, su protección contra sobrecalentamiento gracias a su disipador integrado y la facilidad de mantenimiento que aportan sus terminales roscadas, convirtiéndolo en la opción más confiable para soportar la carga eléctrica del motorreductor amarillo DC a 12V.
Justificación técnica y gestión de potencia

Se tomó la decisión de implementar el driver L298N para separar de forma efectiva la etapa de potencia de la etapa de lógica de control. Al alimentar el motorreductor amarillo DC directamente desde la batería a través del puente H, evitamos que las corrientes parásitas y el ruido inductivo generados por el motor se propaguen hacia la línea regulada de 5V del Arduino Mega 2560.

Esta separación es fundamental para prevenir caídas de voltaje momentáneas que podrían provocar reinicios indeseados en la cámara HuskyLens 2 o causar pérdidas de sincronización en el bus de comunicación I2C de la IMU MPU6050. Asimismo, la capacidad de disipación del L298N nos permite aplicar rampas de aceleración y frenado dinámico por software manteniendo una temperatura de operación estable dentro del rango óptimo de trabajo.

### 3.3 Baterías y Alimentación

### Baterías: Li-Ion 18650

<table>
  <tr>
    <td width="30%" valign="top" align="center">
      <br>
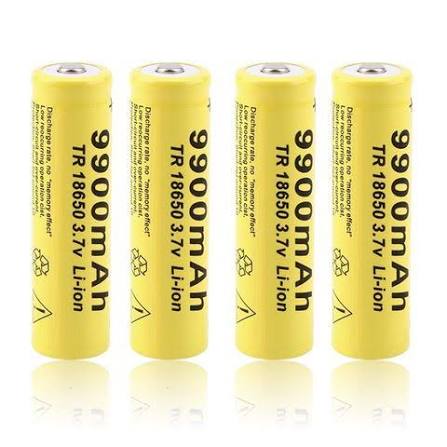
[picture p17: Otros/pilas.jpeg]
Baterías Li-Ion 18650
      
    </td>
    <td valign="top">
      <h4>Especificaciones:</h4>
      <table>
        <tr><td><b>Capacidad nominal</b></td><td>3200 mAh</td></tr>
        <tr><td><b>Voltaje nominal</b></td><td>3,6V DC</td></tr>
        <tr><td><b>Rango de voltaje de operación</b></td><td>4.20V (Carga completa) - 2.5V (Descarga límite)</td></tr>
        <tr><td><b>Corriente de carga máxima</b></td><td>2200 mA</td></tr>
        <tr><td><b>Corriente de descarga máxima</b></td><td>4400 mA</td></tr>
        <tr><td><b>Peso de la celda</b></td><td>44,5g</td></tr>
        <tr><td><b>Datasheet</b></td><td><a href="URL_DEL_DATASHEET" target="_blank">Technical Information NCR18650BF.pdf</a></td></tr>
      </table>
    </td>
  </tr>
</table>

> [!WARNING]
> Nota sobre la capacidad real de las baterías
> 
> Aunque en las baterías se visualiza que poseen una capacidad de 9800 mAh, este valor no suele corresponder a la capacidad real de una pila individual, por lo que, en la práctica, las celdas 18650 confiables tienen una capacidad entre 2200 y 3500 mAh. Hay que tomar en cuenta que las marcas genéricas exageran esa etiqueta con fines publicitarios.

### Motivo de la elección

Las baterías de iones de litio 18650 son la opción más eficiente y rentable para el sistema de energía del robot, ofreciendo una alta densidad energética en un formato compacto y de bajo peso. Cada celda pesa aproximadamente 44,5 gramos y es capaz de entregar corrientes de descarga continua de hasta 4400 mA, lo que garantiza el suministro necesario para cubrir la demanda simultánea del motorreductor amarillo DC, el servomotor MG996R de la dirección, la cámara de visión artificial HuskyLens 2 y los sensores del sistema.

Su química de Li-Ion proporciona un voltaje nominal constante y una curva de descarga estable en comparación con tecnologías tradicionales, garantizando que los circuitos lógicos y los actuadores mantengan un rendimiento óptimo durante todo el tiempo de recorrido en la pista.
Comparación con otras tecnologías de alimentación

Al evaluar diferentes alternativas de almacenamiento de energía para robótica móvil, las celdas 18650 presentan claras ventajas frente a las baterías alcalinas tradicionales, las baterías de NiMH y los paquetes de LiPo (Polímero de Litio):

 * Frente a Baterías Alcalinas / NiMH (AA): Las baterías AA ofrecen una baja densidad de energía y una marcada caída de voltaje bajo consumos elevados. Se requerirían múltiples celdas AA para alcanzar el voltaje de operación del sistema, lo que incrementaría drásticamente el peso del robot y reduciría el tiempo de autonomía.
 * Frente a Baterías LiPo: Aunque las baterías LiPo ofrecen tasas de descarga muy altas, su envoltura blanda las hace vulnerables a perforaciones o daños mecánicos en caso de colisión. Además, requieren cuidados rigurosos de almacenamiento y carga. Las celdas 18650 cuentan con un blindaje metálico cilíndrico rígido que ofrece mayor seguridad estructural dentro del chasis.
 * Frente a Powerbanks USB: Un powerbank comercial limita la salida a 5V regulados mediante circuitos internos que pueden cortar el suministro ante picos repentinos de corriente generados por el servomotor o el motor de tracción. El uso directo de celdas 18650 permite acceder al potencial completo de voltaje de la batería sin restricciones de corriente de protección externas.
   
### Justificación del sistema de alimentación

A diferencia de configuraciones con doble fuente de alimentación, el sistema utiliza un único paquete de baterías 18650 conectadas en serie como fuente centralizada de energía. Esta configuración unificada simplifica la arquitectura eléctrica del robot, reduce el peso total del chasis y optimiza el espacio interno.

El paquete en serie suministra directamente el voltaje de línea principal al módulo driver L298N para energizar la etapa de tracción. A su vez, esta misma línea principal alimenta al microcontrolador Arduino Mega 2560 a través de su puerto de entrada VIN, utilizando sus reguladores internos y los sistemas de conversión para distribuir un voltaje limpio y estable hacia la cámara HuskyLens 2, el giroscopio MPU6050, el servomotor MG996R y los sensores ultrasónicos HC-SR04.

Esta centralización disminuye los puntos de falla en el cableado, facilita el proceso de recarga mediante un único punto de conexión e incluye un interruptor general de corte para proteger la química de las baterías y permitir un encendido y apagado rápido y seguro.
Justificación de la ubicación

El paquete de baterías se posicionó estratégicamente en el costado trasero del chasis. Esta ubicación responde principalmente a la necesidad de equilibrar la distribución de pesos del vehículo:

 * Balance del centro de gravedad: Al estar montados en la sección frontal componentes de peso considerable como el servomotor de dirección MG996R, el soporte de la dirección y la cámara HuskyLens 2, ubicar la batería en el costado trasero compensa la carga sobre el tren delantero, mejorando la tracción de las ruedas traseras y evitando derrapes no deseados en las curvas.

   ### Regulador de Voltaje: LM2596S

<table>
  <tr>
    <td width="30%" valign="top" align="center">
      <br>
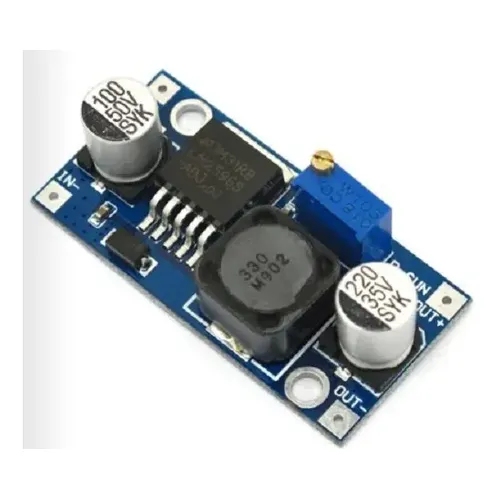
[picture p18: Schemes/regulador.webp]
Módulo Regulador LM2596S
      
    </td>
    <td valign="top">
      <h4>Especificaciones:</h4>
      <table>
        <tr><td><b>Modelo</b></td><td>LM2596S (Módulo DC-DC Step-Down)</td></tr>
        <tr><td><b>Voltaje de entrada</b></td><td>3.2V a 40V DC</td></tr>
        <tr><td><b>Voltaje de salida</b></td><td>1.25V a 35V DC (Ajustable mediante trimpot)</td></tr>
        <tr><td><b>Corriente de salida</b></td><td>2A continua (hasta 3A con disipador)</td></tr>
        <tr><td><b>Eficiencia de conversión</b></td><td>Hasta 92%</td></tr>
        <tr><td><b>Frecuencia de conmutación</b></td><td>150 kHz</td></tr>
        <tr><td><b>Rizado de salida</b></td><td>&lt; 30 mV</td></tr>
        <tr><td><b>Datasheet</b></td><td><a href="https://agelectronica.lat/pdfs/textos/L/LM2596S-DC-DC-MODULE.PDF" target="_blank">LM2596S-DC-DC-MODULE.PDF</a></td></tr>
      </table>
    </td>
  </tr>
</table>

### Motivo de la elección

El módulo regulador conmutado paso a paso (Step-Down Buck) LM2596S fue seleccionado como la columna vertebral de la gestión de voltaje de nuestro robot debido a su alta eficiencia energética (hasta un 92%) y su capacidad para entregar hasta 3A de corriente pico. Dado que el paquete de baterías Li-Ion 18650 suministra un voltaje superior al requerido por los componentes electrónicos, el LM2596S permite reducir y estabilizar dicha tensión con una generación mínima de calor.

Para garantizar un rendimiento óptimo y prevenir fallos eléctricos, se implementó una arquitectura de regulación dual integrada por dos módulos LM2596S independientes:

 * Regulador 1 (Línea Lógica y Visión a 5V): Configurado a una salida constante de 5.0V para alimentar de forma segura e interrumpida la etapa de control y percepción del robot, correspondiente al Arduino Mega 2560, la cámara de visión artificial HuskyLens 2, el giroscopio MPU6050 y los sensores ultrasónicos HC-SR04.
 * Regulador 2 (Línea de Actuación a 7V): Configurado a una salida dedicada de 7.0V exclusivamente para el servomotor de dirección MG996R. Esto permite exprimir al máximo el torque y la velocidad de respuesta del servo (cuyo límite recomendado ronda los 7.2V) sin comprometer ni sobrecargar la línea de 5V de los componentes sensibles.
   
### Comparación con otras soluciones de regulación

Al comparar el LM2596S con reguladores lineales tradicionales (como el regulador interno del Arduino, el LM7805 o el AMS1117), la principal desventaja de los sistemas lineales radica en que convierten todo el exceso de voltaje en calor mediante disipación. Alimentar componentes de alto consumo como la HuskyLens 2 o el servomotor desde un regulador lineal provocaría sobrecalentamiento inmediato, cortes por protección térmica o caídas drásticas de tensión. El LM2596S, al ser un regulador conmutado de 150 kHz, aprovecha la energía con pérdidas insignificantes de temperatura.

Por otro lado, al evaluar la alternativa de utilizar un único regulador central de 5V para todo el sistema, esta opción presenta severas limitaciones operativas: por un lado, limitaría el rendimiento del servomotor MG996R al hacerlo operar a un voltaje menor (perdiendo fuerza de giro y rapidez de respuesta); por otro lado, crearía un riesgo constante de brownouts (reinicio imprevisto del Arduino o de la cámara) producidos por las caídas bruscas de voltaje que exige el servo en situaciones de alta resistencia mecánica.

#### Justificación técnica y aislamiento de cargas

La decisión estratégica de separar la regulación en dos módulos independientes resuelve de raíz el problema de los picos de corriente e inducción electromagnética producidos por el servomotor. Durante los cambios bruscos de dirección o el sostenimiento del ángulo de las ruedas, el servomotor demanda pulsos elevados de corriente que pueden distorsionar la línea de alimentación. Al contar con un LM2596S ajustado exclusivamente a 7V para la dirección, dichos picos de corriente quedan confinados en esa etapa, protegiendo totalmente la estabilidad del bus de 5V.
Asimismo, la posibilidad de calibrar con precisión el voltaje de salida del segundo regulador a 7V proporciona una ventaja competitiva en pista: el servomotor de dirección incrementa significativamente su velocidad angular y su torque de retención en comparación con su operación estándar a 5V. Esto permite al robot ejecutar correcciones de trayectoria más rápidas y precisas al recibir las instrucciones enviadas por la cámara HuskyLens 2 y el giroscopio MPU6050.

### 3.4 Esquemas de Conexión
El conexionado eléctrico integral de potencia, distribución de buses y líneas de control de "Gedeon" fue desarrollado en Cirkitdesigner.

photo_4983464731695844532_y

> [!NOTE]
> Optamos por un sistema de interconexión basado en cableado flexible (cables puente y cable UTP).

## 1. Tabla Principal de Mapeo de Pines (Arduino Mega 2560)

| Subsistema | Componente / Periférico | Pin Físico | Modo de operación / Protocolo de firmware |
| :--- | :--- | :--- | :--- |
| Dirección | Servomotor MG996R Digi High-Torque | Pin 8 | Salida PWM a 50 Hz (Control con Servo.h, rango restringido de 69° a 111°) |
| Tracción | Controlador L298N - ENA (Velocidad) | Pin 2 | Modulación PWM (analogWrite de 8 bits, 0-255) |
|  | Controlador L298N - IN1 (Sentido) | Pin 5 | Salida Digital: Estado ALTO (HIGH) para avance |
|  | Controlador L298N - IN2 (Sentido) | Pin 6 | Salida Digital: Estado BAJO (LOW) para avance / ALTO para freno |
| Orientación | Sensor Inercial IMU MPU6050 (SDA) | Pin 20 | Bus I2C - Línea de datos bidireccional (SDA a 400 kHz Fast-Mode) |
|  | Sensor Inercial IMU MPU6050 (SCL) | Pin 21 | Bus I2C - Línea de reloj (SCL a 400 kHz Fast-Mode) |
| Ultrasonido | HC-SR04 Frontal - TRIGGER | Pin 24 | Salida Digital: Disparo de pulso (10 µs) |
|  | HC-SR04 Frontal - ECHO | Pin 26 | Entrada Digital: Tiempo de retorno medido mediante pulseIn() |
|  | HC-SR04 Derecho - TRIGGER | Pin 38 | Salida Digital: Disparo de pulso (10 µs) |
|  | HC-SR04 Derecho - ECHO | Pin 37 | Entrada Digital: Tiempo de retorno medido mediante pulseIn() |
|  | HC-SR04 Izquierdo - TRIGGER | Pin 39 | Salida Digital: Disparo de pulso (10 µs) |
|  | HC-SR04 Izquierdo - ECHO | Pin 40 | Entrada Digital: Tiempo de retorno medido mediante pulseIn() |

### Cálculo de Autonomía Real en Pista

### 2.2.2 Cálculo de Autonomía Real en Pista

Considerando la capacidad real del banco de litio en configuración 3S ($V_{\text{nom}} = 11.1\text{V}$, $V_{\text{máx}} = 12.6\text{V}$) y una eficiencia promedio del $88\%$ ($\eta = 0.88$) en las conversiones Buck/Boost:

$$I_{\text{promedio}} = \frac{P_{\text{total}}}{\eta \cdot V_{\text{bus}}} = \frac{8.67\text{ W}}{0.88 \cdot 11.1\text{ V}} \approx 0.89\text{ A} \quad \text{(a plena demanda dinámica en carrera)}$$

$$T_{\text{autonomía, activo}} = \frac{3.5\text{ Ah}}{0.89\text{ A}} \approx 3.93\text{ Horas de Navegación Continua}$$

$$T_{\text{autonomía, standby}} = \frac{3.5\text{ Ah}}{0.236\text{ A}} \approx 14.8\text{ Horas de Espera en Boxes}$$

> 💡 Razonamiento del Consumo: Al operar a una tensión nominal superior ($11.1\text{V}$ con 3 celdas en serie), la demanda de corriente promedio se reduce a apenas $0.89\text{ A}$. Esto minimiza la caída por resistencia interna (*I²R*), evita el estrés térmico en las celdas y garantiza una curva de descarga extremadamente estable durante todas las mangas de competencia.

---

### Banco de Baterías 18650 3S (10.5V - 11.1V / 12.6V Máx) y Autonomía Teórica

El suministro energético de la plataforma se basa en celdas de iones de litio de alta densidad energética en arreglo de 3 celdas en serie (3S):

* Topología Eléctrica (3S): Tres celdas conectadas en serie:
  $$V_{\text{nom}} = 3 \times 3.7\text{V} = 11.1\text{V CC} \quad (V_{\text{máx}} = 3 \times 4.2\text{V} = 12.6\text{V a plena carga})$$
  $$C_{\text{total}} = 3500\text{ mAh} \quad (3.5\text{ Ah}) \implies E_{\text{disponible}} = 11.1\text{V} \times 3.5\text{ Ah} = 38.85\text{ Wh}$$

* Estabilidad de Tensión Prolongada: La configuración 3S permite trabajar más cerca del rango óptimo de regulación de los convertidores, reduciendo el trabajo de elevación de voltaje y optimizando la eficiencia global del circuito.

* Repetibilidad en Pista: El vehículo sostiene un rendimiento constante durante más de 3.5 horas de entrenamiento continuo sin caídas drásticas de torque en los motores de tracción ni reinicios en los sensores de la plataforma.

## 4. Software y Control
Ronda abierta 

Estructura y Funcionamiento del Código
Navegación Híbrida (Ultrasonidos + MPU6050):

Los sensores ultrasónicos (PIN_TRIG_FRONTAL, DERECHO, IZQUIERDO) miden constantemente el espacio libre para detectar las paredes y anticiparse a las curvas.

El giroscopio MPU6050 se actualiza en segundo plano mediante la función actualizarMPU() para calcular con alta precisión la orientación actual del robot (Yaw), permitiéndole mantener la línea recta o girar exactamente 90 grados sin perder el rumbo.

Control Estricto de Dirección (Servo):

Utiliza los límites de calibración del servo (ANGULO_MINIMO de 69° y ANGULO_MAXIMO de 111° con centro en 90°) para evitar sobreesfuerzos mecánicos.

Emplea un control proporcional (KP = 1.2f) para realizar correcciones suaves y dinámicas sobre el ángulo de las ruedas basándose en la distancia a los muros laterales.

Conteo de Esquinas (Vueltas):

El robot monitorea la distancia frontal (DISTANCIA_DETECCION_CURVA = 38.0f). Cuando se acerca a una pared o esquina, activa un giro controlado hacia la dirección predeterminada (GIRAR_HACIA_IZQUIERDA = true).

Cada vez que completa un giro, incrementa la variable esquinas_contadas. Al llegar a las TOTAL_CURVAS_OBJETIVO = 12 (las 4 esquinas de cada una de las 3 vueltas), el programa frena los motores por completo y finaliza la carrera de forma autónoma.

Esquive de Obstáculos Genéricos Integrado:

Cuenta con una subrutina preventiva (DIST_DETECCION_OBSTACULO = 45.0f) que le permite evaluar si hay un objeto imprevisto en la pista, comparando los lados izquierdo y derecho para decidir hacia qué costado maniobrar de forma segura antes de retomar el circuito.

Diagnóstico por Monitor Serie:

Gracias a la directiva #define DEBUG_SERIAL 1, el sistema imprime constantemente en tiempo real los valores de los sensores y el estado del robot, lo que facilita enormemente la depuración y calibración en la pista de competencia.
/**
 * ============================================================================
 * WRO FUTURE ENGINEERS - NAVEGACIÓN HÍBRIDA (ULTRASONIDOS + MPU6050)
 * + ESQUIVE DE OBSTÁCULOS GENÉRICOS + DIAGNÓSTICO POR SERIAL
 * IDE: Arduino IDE
 *
 * Código COMPLETO unificado.
 * INCLUYE: Calibración estricta de ±21 grados para el servo MG996R.
 * (Centro: 90°, Mínimo: 69°, Máximo: 111°)
 * ============================================================================
 */

#include <Arduino.h>
#include <Servo.h>
#include <Wire.h>
#include <Adafruit_MPU6050.h>
#include <Adafruit_Sensor.h>

// ========================================================
// MAPEO DE PINES 
// ========================================================
constexpr uint8_t PIN_SERVO_DIRECCION = 8;
constexpr uint8_t PIN_L298N_ENA = 2;
constexpr uint8_t PIN_L298N_IN1 = 5;
constexpr uint8_t PIN_L298N_IN2 = 6;

constexpr uint8_t PIN_TRIG_FRONTAL = 24;
constexpr uint8_t PIN_ECHO_FRONTAL = 26;
constexpr uint8_t PIN_TRIG_DERECHO = 38;
constexpr uint8_t PIN_ECHO_DERECHO = 37;
constexpr uint8_t PIN_TRIG_IZQUIERDO = 39;
constexpr uint8_t PIN_ECHO_IZQUIERDO = 40;

// ========================================================
// CONFIGURACIÓN DE COMPETENCIA
// ========================================================
constexpr int TOTAL_CURVAS_OBJETIVO = 12;
constexpr float DISTANCIA_DETECCION_CURVA = 38.0f;

constexpr bool GIRAR_HACIA_IZQUIERDA = true;

constexpr int VELOCIDAD_AVANCE = 140;
constexpr int VELOCIDAD_FRENADO = 0;
constexpr int VELOCIDAD_GIRO = 120;

// --- CALIBRACIÓN EXACTA DEL SERVO ---
constexpr int SERVO_CENTRO = 90;
constexpr int DEFLEXION_MAXIMA = 21; // <-- Aplicado tu límite de ±21 grados
constexpr int ANGULO_MINIMO = SERVO_CENTRO - DEFLEXION_MAXIMA; // 69 grados
constexpr int ANGULO_MAXIMO = SERVO_CENTRO + DEFLEXION_MAXIMA; // 111 grados

constexpr float KP = 1.2f;
constexpr float MAX_DIST_VALIDA = 80.0f;

// --------------------------------------------------------
// ESQUIVAR OBSTÁCULOS GENÉRICOS
// --------------------------------------------------------
constexpr float DIST_DETECCION_OBSTACULO = 45.0f; // mayor que DISTANCIA_DETECCION_CURVA
constexpr float DIST_MARGEN_LIBRE = 30.0f;        // umbral para considerar un lado "libre"
constexpr int VELOCIDAD_ESQUIVE = 110;

bool esquivando_obstaculo = false;

// --------------------------------------------------------
// DIAGNÓSTICO POR SERIAL
// --------------------------------------------------------
#define DEBUG_SERIAL 1
unsigned long tiempo_ultimo_debug = 0;

// ========================================================
// VARIABLES GLOBALES
// ========================================================
Servo servoDireccion;
Adafruit_MPU6050 mpu;

int esquinas_contadas = 0;
bool carrera_terminada = false;
unsigned long tiempo_ultimo_giro = 0;
constexpr unsigned long COOLDOWN_GIRO_MS = 1200;

float dist_izq_filtrada = 0.0f;
float dist_der_filtrada = 0.0f;

float yaw_actual = 0.0f;
float gz_offset = 0.0f;
unsigned long tiempo_ultimo_mpu = 0;

// ========================================================
// FUNCIONES AUXILIARES
// ========================================================
void actualizarMPU() {
  unsigned long tiempo_actual_us = micros();
  if (tiempo_actual_us - tiempo_ultimo_mpu >= 2000) {
    float dt = (tiempo_actual_us - tiempo_ultimo_mpu) / 1000000.0f;
    tiempo_ultimo_mpu = tiempo_actual_us;

    sensors_event_t a, g, temp;
    mpu.getEvent(&a, &g, &temp);

    float gz = g.gyro.z - gz_offset;
    if (abs(gz) > 0.015f) {
      yaw_actual += (gz * RAD_TO_DEG) * dt;
    }
  }
}

float leerUltrasonico(uint8_t pinTrig, uint8_t pinEcho) {
  digitalWrite(pinTrig, LOW);
  delayMicroseconds(2);
  digitalWrite(pinTrig, HIGH);
  delayMicroseconds(10);
  digitalWrite(pinTrig, LOW);

  long duracion = pulseIn(pinEcho, HIGH, 30000); // ~5m máx, timeout generoso para diagnosticar
  if (duracion == 0) return MAX_DIST_VALIDA; // sin eco = "sin obstáculo válido"
  return (duracion * 0.0343f) / 2.0f;
}
photo_4983786265832525412_y

Ronda Cerrada

Este código implementa la estrategia para la Segunda Ronda de la categoría Future Engineers de la WRO, la cual incorpora la prueba de evasión de obstáculos (pilares o bloques distribuidos en la pista) además de completar el recorrido.

Diferenciación entre Esquina y Obstáculo: El sistema evalúa el sensor frontal. Si la distancia es menor a DIST_DETECCION_OBSTACULO (45 cm), el código discierne si se trata de una pared de una esquina (cuando ambos lados están bloqueados) o de un obstáculo flotante en la pista (cuando al menos un lateral está libre).

Maniobra de Esquive Dinámico: Al detectar un obstáculo y verificar qué costado tiene mayor espacio libre (izq_libre o der_libre), el robot ajusta el ángulo del servo hacia el lado óptimo y reduce la velocidad de tracción (VELOCIDAD_ESQUIVE) para rodear la pieza con precisión.

Navegación por Carril (Control Proporcional): Fuera de las situaciones de esquive o giros de 90 grados, el sistema calcula el error entre los sensores ultrasónicos izquierdo y derecho aplicando la constante KP = 1.2f para mantener el vehículo centrado en las rectas.

Protección Mecánica del Servo: Todas las órdenes de dirección pasan por la función escribirServo(), la cual restringe estrictamente el movimiento entre el ángulo mínimo (69°) y el máximo (111°), tomando como base el centro de 90° para proteger el mecanismo de la dirección.

Control de Giro por Giroscopio (MPU6050): Al llegar a una esquina real, frena momentáneamente e integra el ángulo de "Yaw" medido por el giroscopio para asegurar un giro preciso de 90 grados antes de reanudar la marcha y contabilizar la esquina.

 * ============================================================================
 * WRO FUTURE ENGINEERS - NAVEGACIÓN HÍBRIDA (ULTRASONIDOS + MPU6050)
 * + ESQUIVE DE OBSTÁCULOS GENÉRICOS + DIAGNÓSTICO POR SERIAL
 * IDE: Arduino IDE
 *
 * Código COMPLETO unificado.
 * INCLUYE: Calibración estricta de ±21 grados para el servo MG996R.
 * (Centro: 90°, Mínimo: 69°, Máximo: 111°)
 * ============================================================================
 */#include <Arduino.h>#include <Servo.h>#include <Wire.h>#include <Adafruit_MPU6050.h>#include <Adafruit_Sensor.h>

// ========================================================
// MAPEO DE PINES 
// ========================================================
constexpr uint8_t PIN_SERVO_DIRECCION = 8;
constexpr uint8_t PIN_L298N_ENA = 2;
constexpr uint8_t PIN_L298N_IN1 = 5;
constexpr uint8_t PIN_L298N_IN2 = 6;

constexpr uint8_t PIN_TRIG_FRONTAL = 24;
constexpr uint8_t PIN_ECHO_FRONTAL = 26;
constexpr uint8_t PIN_TRIG_DERECHO = 38;
constexpr uint8_t PIN_ECHO_DERECHO = 37;
constexpr uint8_t PIN_TRIG_IZQUIERDO = 39;
constexpr uint8_t PIN_ECHO_IZQUIERDO = 40;

// ========================================================
// CONFIGURACIÓN DE COMPETENCIA
// ========================================================
constexpr int TOTAL_CURVAS_OBJETIVO = 12;
constexpr float DISTANCIA_DETECCION_CURVA = 38.0f;

constexpr bool GIRAR_HACIA_IZQUIERDA = true;

constexpr int VELOCIDAD_AVANCE = 140;
constexpr int VELOCIDAD_FRENADO = 0;
constexpr int VELOCIDAD_GIRO = 120;

// --- CALIBRACIÓN EXACTA DEL SERVO ---
constexpr int SERVO_CENTRO = 90;
constexpr int DEFLEXION_MAXIMA = 21; // <-- Aplicado tu límite de ±21 grados
constexpr int ANGULO_MINIMO = SERVO_CENTRO - DEFLEXION_MAXIMA; // 69 grados
constexpr int ANGULO_MAXIMO = SERVO_CENTRO + DEFLEXION_MAXIMA; // 111 grados

constexpr float KP = 1.2f;
constexpr float MAX_DIST_VALIDA = 80.0f;

// --------------------------------------------------------
// ESQUIVAR OBSTÁCULOS GENÉRICOS
// --------------------------------------------------------
constexpr float DIST_DETECCION_OBSTACULO = 45.0f; // mayor que DISTANCIA_DETECCION_CURVA
constexpr float DIST_MARGEN_LIBRE = 30.0f;        // umbral para considerar un lado "libre"
constexpr int VELOCIDAD_ESQUIVE = 110;

bool esquivando_obstaculo = false;

// --------------------------------------------------------
// DIAGNÓSTICO POR SERIAL
// --------------------------------------------------------#define DEBUG_SERIAL 1
unsigned long tiempo_ultimo_debug = 0;

// ========================================================
// VARIABLES GLOBALES
// ========================================================
Servo servoDireccion;
Adafruit_MPU6050 mpu;

int esquinas_contadas = 0;
bool carrera_terminada = false;
unsigned long tiempo_ultimo_giro = 0;
constexpr unsigned long COOLDOWN_GIRO_MS = 1200;

float dist_izq_filtrada = 0.0f;
float dist_der_filtrada = 0.0f;

float yaw_actual = 0.0f;
float gz_offset = 0.0f;
unsigned long tiempo_ultimo_mpu = 0;

// ========================================================
// FUNCIONES AUXILIARES
// ========================================================
void actualizarMPU() {
  unsigned long tiempo_actual_us = micros();
  if (tiempo_actual_us - tiempo_ultimo_mpu >= 2000) {
    float dt = (tiempo_actual_us - tiempo_ultimo_mpu) / 1000000.0f;
    tiempo_ultimo_mpu = tiempo_actual_us;

    sensors_event_t a, g, temp;
    mpu.getEvent(&a, &g, &temp);

    float gz = g.gyro.z - gz_offset;
    if (abs(gz) > 0.015f) {
      yaw_actual += (gz * RAD_TO_DEG) * dt;
    }
  }
}

float leerUltrasonico(uint8_t pinTrig, uint8_t pinEcho) {
  digitalWrite(pinTrig, LOW);
  delayMicroseconds(2);
  digitalWrite(pinTrig, HIGH);
  delayMicroseconds(10);
  digitalWrite(pinTrig, LOW);

  long duracion = pulseIn(pinEcho, HIGH, 30000); // ~5m máx, timeout generoso para diagnosticar
  if (duracion == 0) return MAX_DIST_VALIDA; // sin eco = "sin obstáculo válido"
  return (duracion * 0.0343f) / 2.0f;
}
void moverMotor(int velocidad) {
  if (velocidad > 0) {
    digitalWrite(PIN_L298N_IN1, HIGH);
    digitalWrite(PIN_L298N_IN2, LOW);
    analogWrite(PIN_L298N_ENA, constrain(velocidad, 0, 255));
  } else if (velocidad < 0) {
    digitalWrite(PIN_L298N_IN1, LOW);
    digitalWrite(PIN_L298N_IN2, HIGH);
    analogWrite(PIN_L298N_ENA, constrain(-velocidad, 0, 255));
  } else {
    digitalWrite(PIN_L298N_IN1, LOW);
    digitalWrite(PIN_L298N_IN2, LOW);
    analogWrite(PIN_L298N_ENA, 0);
  }
}

void escribirServo(int grados) {
  // Asegura estrictamente que el servo no pase de tus 69 y 111 grados
  int angulo_seguro = constrain(grados, ANGULO_MINIMO, ANGULO_MAXIMO);
  servoDireccion.write(angulo_seguro);
}

// ========================================================
// SETUP Y CALIBRACIÓN
// ========================================================
void setup() {
  Serial.begin(115200);
  Wire.begin();
  Wire.setClock(400000);

  pinMode(PIN_TRIG_FRONTAL, OUTPUT); pinMode(PIN_ECHO_FRONTAL, INPUT);
  pinMode(PIN_TRIG_DERECHO, OUTPUT); pinMode(PIN_ECHO_DERECHO, INPUT);
  pinMode(PIN_TRIG_IZQUIERDO, OUTPUT); pinMode(PIN_ECHO_IZQUIERDO, INPUT);

  pinMode(PIN_L298N_ENA, OUTPUT);
  pinMode(PIN_L298N_IN1, OUTPUT);
  pinMode(PIN_L298N_IN2, OUTPUT);
  moverMotor(0);

  servoDireccion.attach(PIN_SERVO_DIRECCION);
  escribirServo(SERVO_CENTRO);#if DEBUG_SERIAL
  Serial.println(F("=== TEST DE SENSORES ANTES DE ARRANCAR ==="));
  for (int i = 0; i < 5; i++) {
    float f = leerUltrasonico(PIN_TRIG_FRONTAL, PIN_ECHO_FRONTAL);
    float l = leerUltrasonico(PIN_TRIG_IZQUIERDO, PIN_ECHO_IZQUIERDO);
    float r = leerUltrasonico(PIN_TRIG_DERECHO, PIN_ECHO_DERECHO);
    Serial.print(F("Frontal: ")); Serial.print(f);
    Serial.print(F(" cm | Izquierdo: ")); Serial.print(l);
    Serial.print(F(" cm | Derecho: ")); Serial.print(r);
    Serial.println(F(" cm"));
    delay(300);
  }
  Serial.println(F("=== Si algún valor se queda fijo en 80.00, ese sensor no responde ==="));#endif

  if (!mpu.begin()) {#if DEBUG_SERIAL
    Serial.println(F("ERROR: MPU6050 no detectado. Revisa cableado I2C."));#endif
    while (1) { delay(10); }
  }

  mpu.setGyroRange(MPU6050_RANGE_500_DEG);
  mpu.setFilterBandwidth(MPU6050_BAND_21_HZ);

  delay(1000);
  float acumulador = 0;
  for (int i = 0; i < 500; i++) {
    sensors_event_t a, g, temp;
    mpu.getEvent(&a, &g, &temp);
    acumulador += g.gyro.z;
    delay(2);
  }
  gz_offset = acumulador / 500.0f;
  yaw_actual = 0.0f;
  tiempo_ultimo_mpu = micros();

  delay(2000);
  dist_izq_filtrada = leerUltrasonico(PIN_TRIG_IZQUIERDO, PIN_ECHO_IZQUIERDO);
  dist_der_filtrada = leerUltrasonico(PIN_TRIG_DERECHO, PIN_ECHO_DERECHO);#if DEBUG_SERIAL
  Serial.println(F("=== Arrancando en 3 segundos... ==="));
  delay(3000);#endif

  moverMotor(VELOCIDAD_AVANCE);
}

// ========================================================
// LOOP PRINCIPAL
// ========================================================
void loop() {
  unsigned long tiempo_actual = millis();

  actualizarMPU();

  if (esquinas_contadas >= TOTAL_CURVAS_OBJETIVO) {
    if (!carrera_terminada) {
      moverMotor(0);
      escribirServo(SERVO_CENTRO);
      carrera_terminada = true;#if DEBUG_SERIAL
      Serial.println(F("=== CARRERA TERMINADA ==="));#endif
    }
    return;
  }

  float dist_front = leerUltrasonico(PIN_TRIG_FRONTAL, PIN_ECHO_FRONTAL);
  actualizarMPU();
  float dist_izq_raw = leerUltrasonico(PIN_TRIG_IZQUIERDO, PIN_ECHO_IZQUIERDO);
  actualizarMPU();
  float dist_der_raw = leerUltrasonico(PIN_TRIG_DERECHO, PIN_ECHO_DERECHO);

  dist_izq_filtrada = (dist_izq_raw * 0.4f) + (dist_izq_filtrada * 0.6f);
  dist_der_filtrada = (dist_der_raw * 0.4f) + (dist_der_filtrada * 0.6f);

  bool izq_libre = dist_izq_filtrada > DIST_MARGEN_LIBRE;
  bool der_libre = dist_der_filtrada > DIST_MARGEN_LIBRE;
#if DEBUG_SERIAL
  // Imprime cada ~200ms para no saturar el Serial Monitor
  if (tiempo_actual - tiempo_ultimo_debug > 200) {
    tiempo_ultimo_debug = tiempo_actual;
    Serial.print(F("F=")); Serial.print(dist_front);
    Serial.print(F(" I=")); Serial.print(dist_izq_filtrada);
    Serial.print(F(" D=")); Serial.print(dist_der_filtrada);
    Serial.print(F(" | IzqLibre=")); Serial.print(izq_libre);
    Serial.print(F(" DerLibre=")); Serial.print(der_libre);
    Serial.print(F(" | esquinas=")); Serial.print(esquinas_contadas);
    Serial.print(F(" | esquivando=")); Serial.println(esquivando_obstaculo);
  }#endif

  // --------------------------------------------------------
  // Si hay algo al frente: decidir PARED DE ESQUINA vs OBSTÁCULO
  // --------------------------------------------------------
  if (dist_front < DIST_DETECCION_OBSTACULO) {

    bool es_pared_de_esquina = (!izq_libre && !der_libre)
                               && (dist_front < DISTANCIA_DETECCION_CURVA)
                               && (tiempo_actual - tiempo_ultimo_giro > COOLDOWN_GIRO_MS);

    if (es_pared_de_esquina) {#if DEBUG_SERIAL
      Serial.println(F(">>> PARED DE ESQUINA DETECTADA: girando 90 grados"));#endif
      moverMotor(VELOCIDAD_FRENADO);
      delay(100);

      float yaw_objetivo = yaw_actual + (GIRAR_HACIA_IZQUIERDA ? 90.0f : -90.0f);

      escribirServo(GIRAR_HACIA_IZQUIERDA ? ANGULO_MAXIMO : ANGULO_MINIMO);
      moverMotor(VELOCIDAD_GIRO);

      unsigned long inicio_giro = millis();
      while (abs(yaw_actual - yaw_objetivo) > 4.0f) {
        actualizarMPU();
        if (millis() - inicio_giro > 2000) {#if DEBUG_SERIAL
          Serial.println(F(">>> TIMEOUT en giro (posible atasco o MPU sin responder)"));#endif
          yaw_actual = yaw_objetivo;
          break;
        }
      }

      esquinas_contadas++;
      tiempo_ultimo_giro = millis();
      esquivando_obstaculo = false;

      escribirServo(SERVO_CENTRO);
      moverMotor(VELOCIDAD_AVANCE);

      dist_izq_filtrada = leerUltrasonico(PIN_TRIG_IZQUIERDO, PIN_ECHO_IZQUIERDO);
      dist_der_filtrada = leerUltrasonico(PIN_TRIG_DERECHO, PIN_ECHO_DERECHO);

      return;
    }
    else if (izq_libre || der_libre) {#if DEBUG_SERIAL
      Serial.println(F(">>> OBSTACULO DETECTADO: esquivando"));#endif
      esquivando_obstaculo = true;

      bool girar_hacia_izquierda_ahora =
          izq_libre && (!der_libre || dist_izq_filtrada >= dist_der_filtrada);

      escribirServo(girar_hacia_izquierda_ahora ? ANGULO_MAXIMO : ANGULO_MINIMO);
      moverMotor(VELOCIDAD_ESQUIVE);
      return;
    }#if DEBUG_SERIAL
    else {
      Serial.println(F(">>> Objeto muy cerca, sin espacio a ningun lado: avanzando normal"));
    }#endif
  }
  else if (esquivando_obstaculo) {
    esquivando_obstaculo = false;
    escribirServo(SERVO_CENTRO);
    moverMotor(VELOCIDAD_AVANCE);
  }

  // Control Proporcional para centrado de carril en rectas
  float error = 0.0f;

  if (dist_izq_filtrada < MAX_DIST_VALIDA && dist_der_filtrada < MAX_DIST_VALIDA) {
    error = dist_izq_filtrada - dist_der_filtrada;
  }
  else if (dist_izq_filtrada < MAX_DIST_VALIDA) {
    error = dist_izq_filtrada - 20.0f;
  }
  else if (dist_der_filtrada < MAX_DIST_VALIDA) {
    error = 20.0f - dist_der_filtrada;
  }

  if (abs(error) < 2.0f) {
    error = 0;
  }

  float correccion = error * KP;
  // escribirServo limitará internamente a los ±21 grados que definimos al inicio
  escribirServo(SERVO_CENTRO + (int)correccion);

  if (!esquivando_obstaculo) {
    moverMotor(VELOCIDAD_AVANCE);
  }

  photo_4983786265832525413_y

### 4.1 Visión Artificial
Procesamiento de imagen y detección de señales/líneas.
Procesamiento de imagen integrado y detección de líneas/señales para navegación autónoma.

La integración de la HuskyLens 2 en el sistema aporta procesamiento de visión artificial embebido, evitando saturar el microcontrolador principal con la carga pesada de procesar pixeles. Sus dos funciones clave para el guiado son:

Procesamiento de Imagen a Bordo: El sensor cuenta con un procesador de inteligencia artificial interno (KPU) que maneja de forma nativa la captura, el filtrado de ruido, la corrección de iluminación y el reconocimiento de patrones. Esto permite entregar directamente al controlador (como un Arduino o ESP32) las coordenadas simplificadas de los objetos o vectores detectados a través de protocolos como I2C o UART, en lugar de matrices de imagen crudas.

Detección de Líneas y Seguimiento: Utiliza algoritmos optimizados de rastreo de trayectorias. La HuskyLens procesa en tiempo real el flujo de la pista, calcula el vector de dirección o ángulo de desviación (coordenadas de los extremos de la línea) y permite que el sistema de control corrija el rumbo de manera fluida.

Reconocimiento de Señales y Etiquetas: Mediante aprendizaje supervisado (AI object tracking o códigos visuales/etiquetas), el módulo identifica marcas geométricas, cruces o señales impresas en el trayecto. Al reconocerlas, genera una ID única que el microprocesador lee instantáneamente para activar eventos lógicos (giros, paradas o cambios de velocidad).

### 4.2 Algoritmo de Navegación
Lógica de esquivar obstáculos y recorrido.

Lógica de esquiva de obstáculos y recorrido.

El flujo de control para la navegación autónoma combina la información visual de la HuskyLens 2 con datos de proximidad (sensores ultrasónicos o infrarrojos) y odometría para lograr un desplazamiento fluido y seguro. La estructura del algoritmo se divide en los siguientes bloques de decisión:

Control de Recorrido (Path Tracking): El microcontrolador procesa el vector de dirección o el ángulo de error entregado en tiempo real por la HuskyLens 2. Mediante un lazo de control, se ajusta la velocidad o el ángulo de dirección para mantener el robot centrado en la trayectoria marcada, corrigiendo desvíos de forma dinámica.

Monitoreo de Proximidad: En paralelo al seguimiento de pista, se lee constantemente el estado de los sensores de distancia frontales y laterales. Si un objeto imprevisto irrumpe en el radio de seguridad, el sistema prioriza la seguridad física del robot por encima del seguimiento visual.

Maniobra de Evasión (Bypass): Al detectar un obstáculo en la ruta, el algoritmo ejecuta una secuencia evasiva: desaceleración controlada, giro para rodear el objeto, avance de compensación y reorientación para buscar nuevamente la línea o el punto de control del circuito.

Gobernanza por Máquina de Estados: Un sistema de estados finitos gestiona las prioridades de movimiento, alternando entre el modo de Seguimiento de Ruta y el modo de Evasión de Obstáculos, asegurando que el robot retome su rumbo original de manera automática una vez que el camino se encuentre despejado.

---

En este repositorio se encuentra la documentación completa de nuestro trabajo para la categoría Future Engineers: desde el diseño mecánico y la selección de componentes, hasta el desarrollo del software, los protocolos de prueba y la evolución de nuestro prototipo.

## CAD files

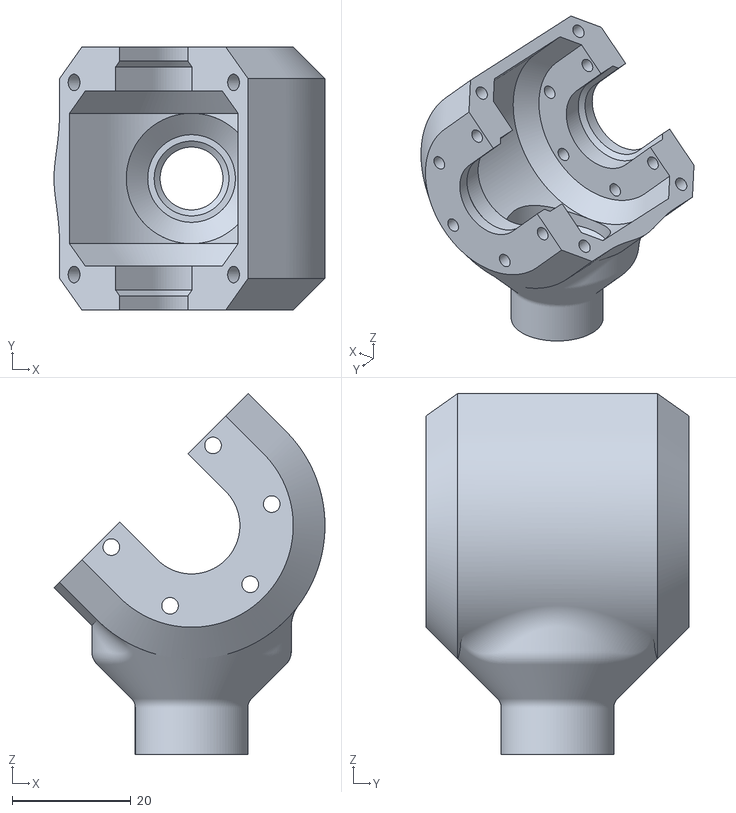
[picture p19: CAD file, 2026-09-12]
Modelos/pumpkin-main.stl
45.7 x 44.4 x 60.9

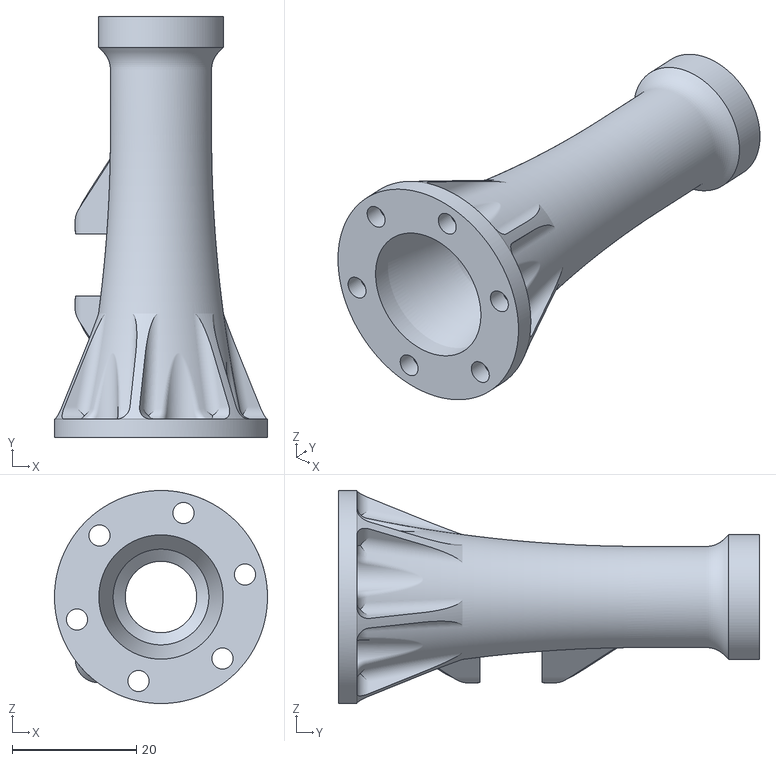
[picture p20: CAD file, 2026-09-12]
Modelos/axle-tube.stl
34.3 x 67.8 x 34.3

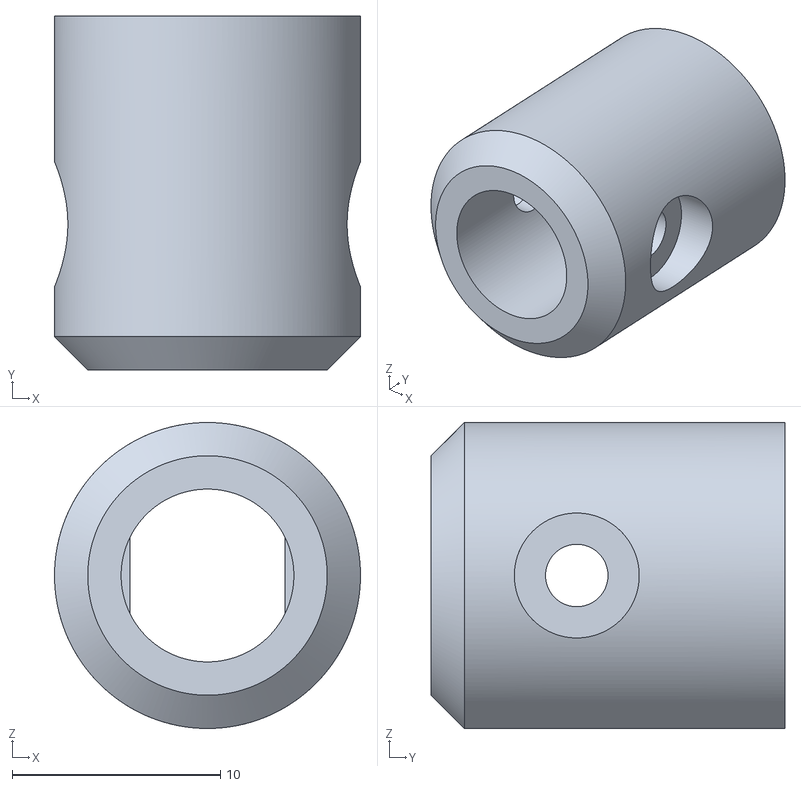
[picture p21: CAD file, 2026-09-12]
Modelos/side-gear-drive-cup.stl
14.7 x 17.0 x 14.7

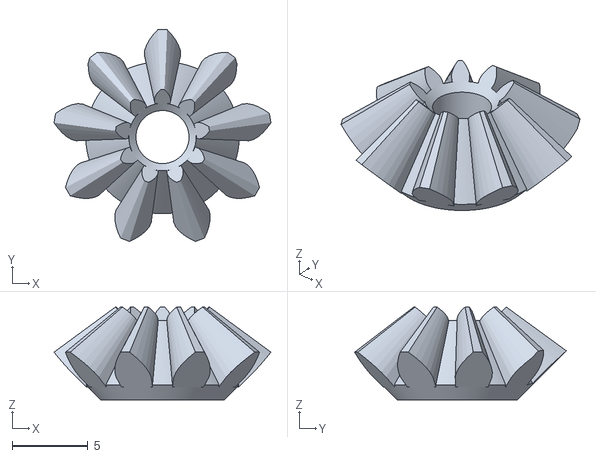
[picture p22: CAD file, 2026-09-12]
Modelos/spider-gear.stl
14.3 x 14.0 x 6.14

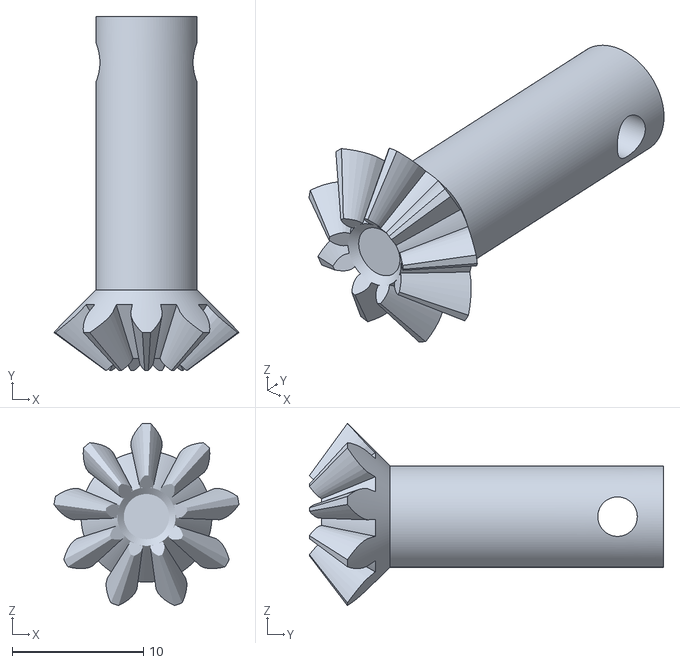
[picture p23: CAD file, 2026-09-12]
Modelos/side-gear.stl
14.1 x 26.9 x 13.9

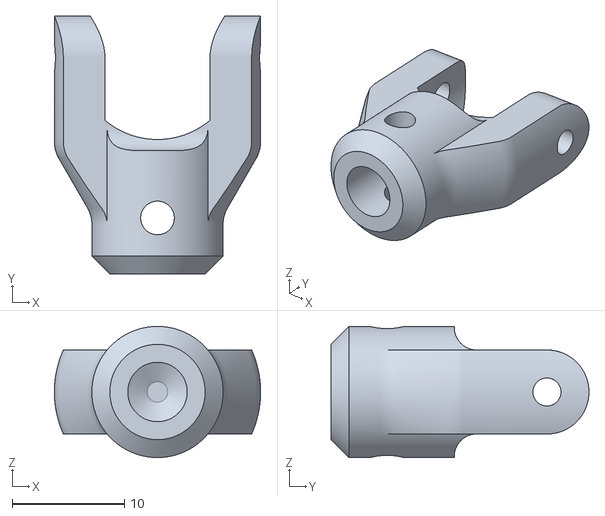
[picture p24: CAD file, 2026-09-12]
Modelos/cup-5mm.stl
18.4 x 23.0 x 11.7

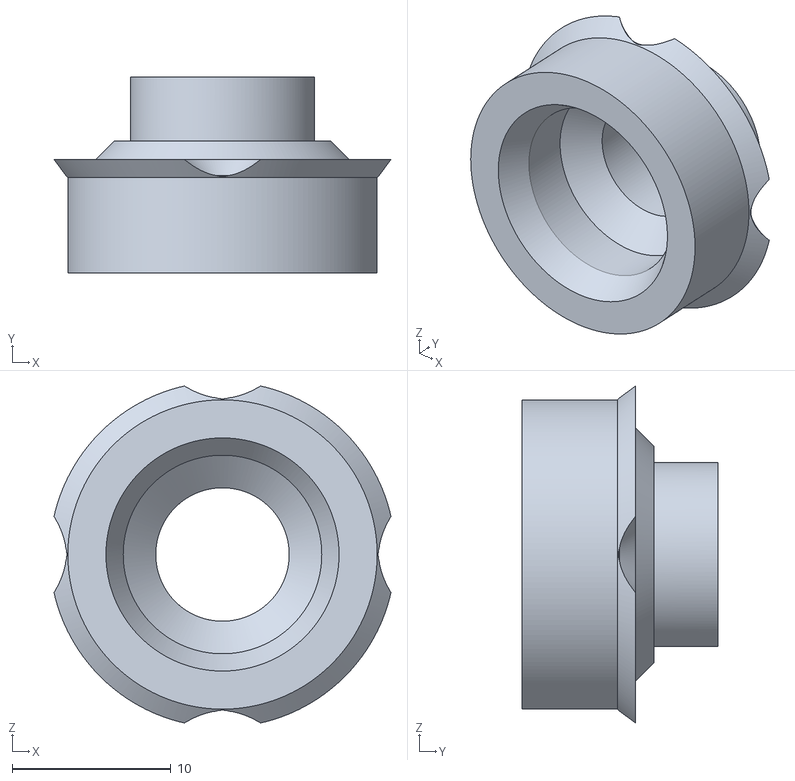
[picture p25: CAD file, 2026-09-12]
Modelos/casing-short.stl
21.2 x 12.3 x 21.2

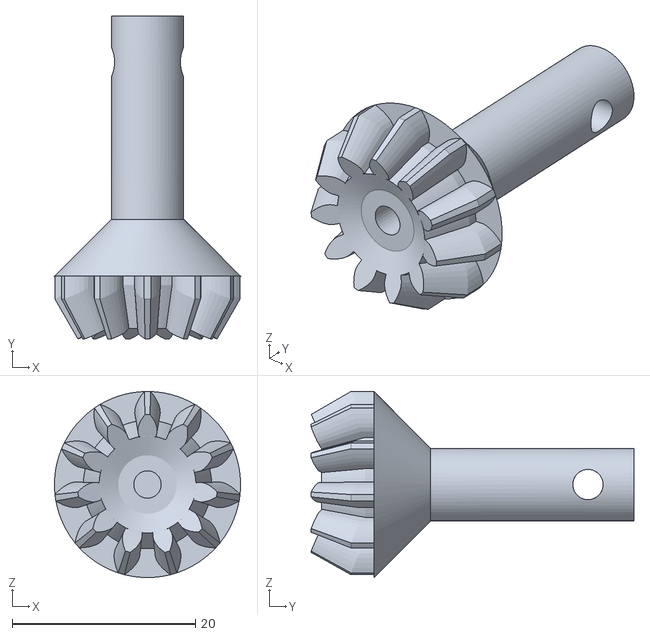
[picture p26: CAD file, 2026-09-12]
Modelos/pinion-gear-23t-mod1pt6-pa25deg-0pt1-clearance.stl
20.3 x 35.2 x 20.3

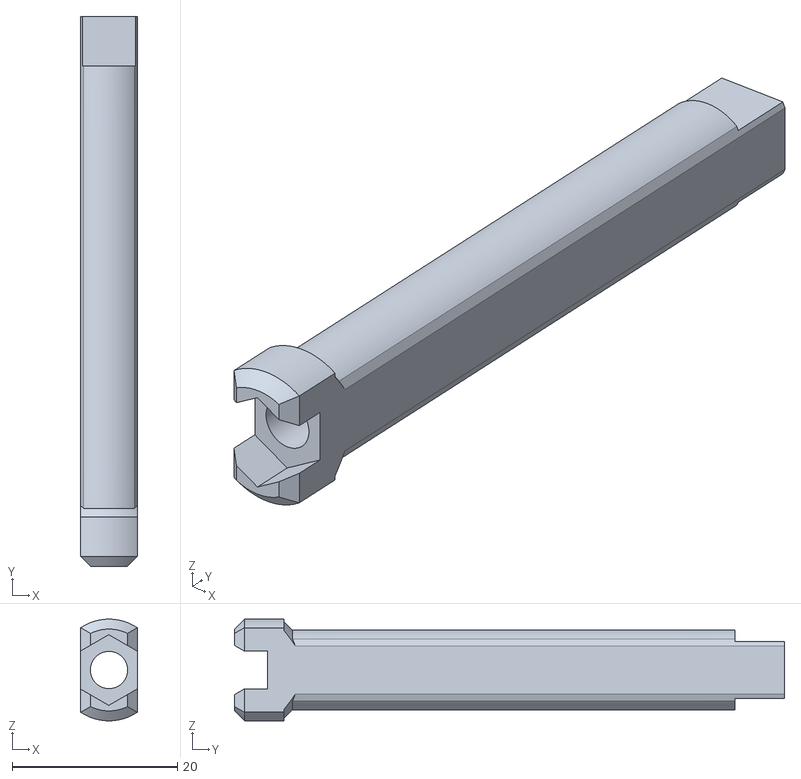
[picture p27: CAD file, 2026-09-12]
Modelos/drive-shaft.stl
6.86 x 66.5 x 12.3

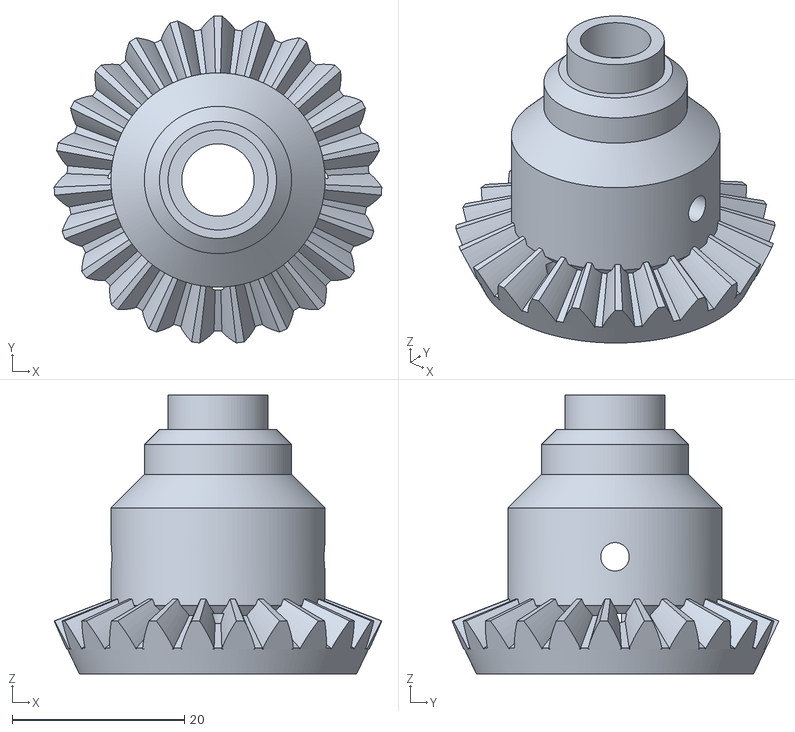
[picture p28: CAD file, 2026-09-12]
Modelos/casing-long.stl
38.1 x 38.0 x 32.4

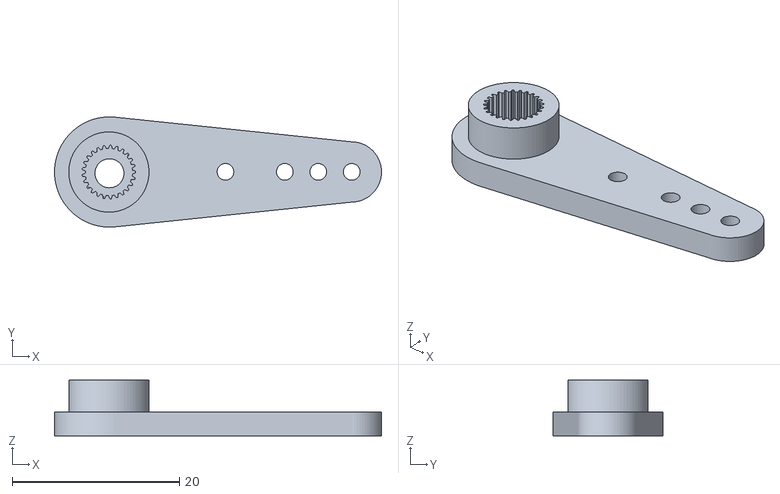
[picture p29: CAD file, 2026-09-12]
Modelos/Servo_Arm.stl
39.1 x 13.2 x 6.68

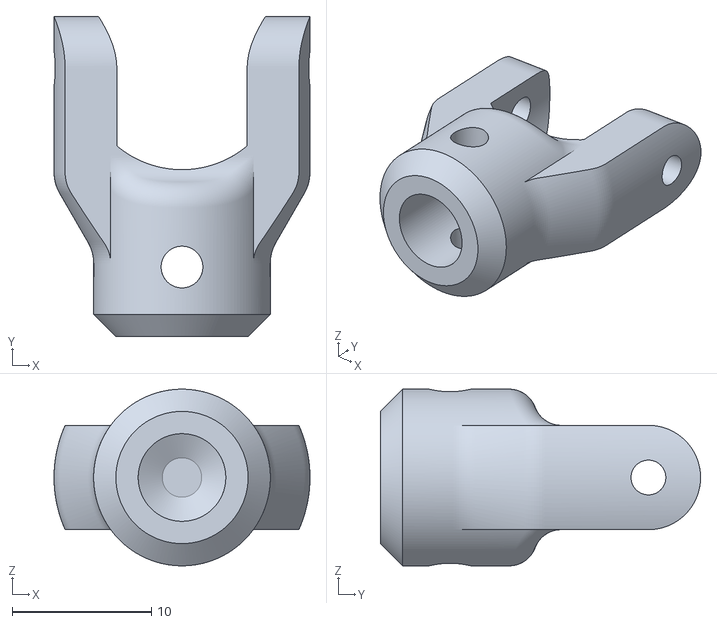
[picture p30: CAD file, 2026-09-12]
Modelos/cup-6mm.stl
18.4 x 23.0 x 12.7

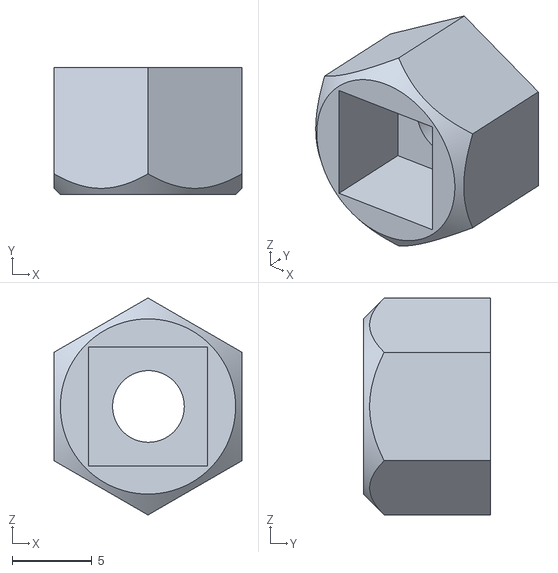
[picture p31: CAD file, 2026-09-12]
Modelos/12mm-hex.stl
11.8 x 8.00 x 13.6

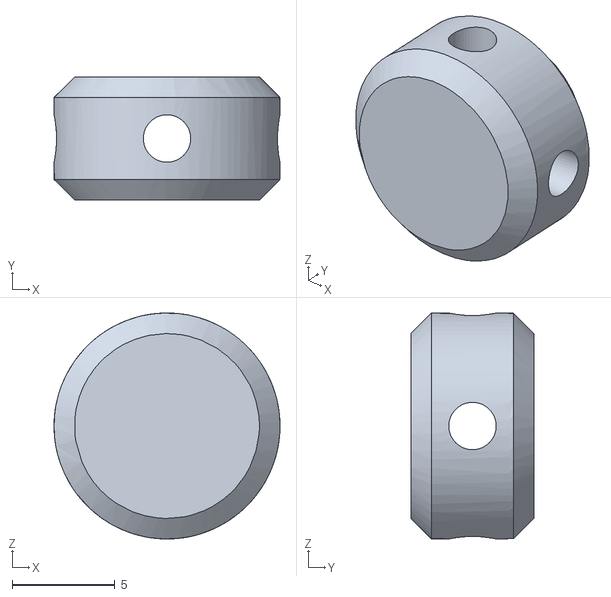
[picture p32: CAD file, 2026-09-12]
Modelos/Cruceta circular.stl
11.0 x 6.00 x 11.0

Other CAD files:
Modelos/pumpkin-cover.stl
